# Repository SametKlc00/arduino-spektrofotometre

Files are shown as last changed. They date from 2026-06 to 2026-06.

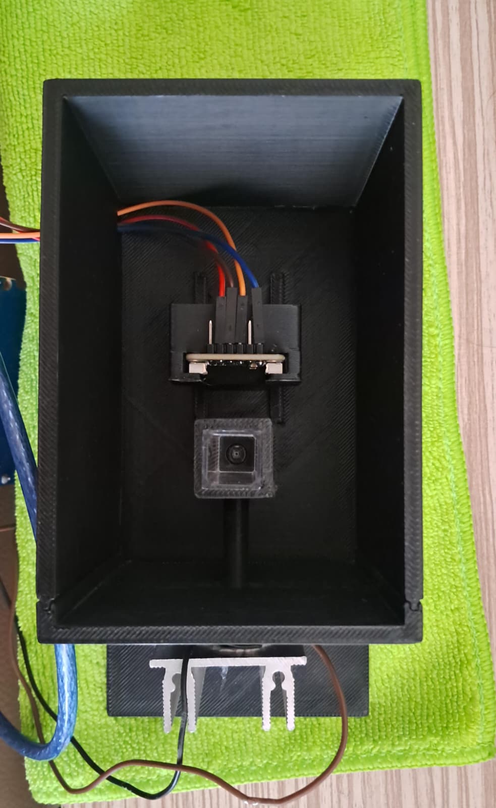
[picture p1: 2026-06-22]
spektrofotometre_devir_paketi_tsl2591/04_Gorseller/WhatsApp Image 2026-06-11 at 16.28.41.jpeg

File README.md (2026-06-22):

# Arduino Tabanlı Düşük Maliyetli Spektrofotometre

Bu proje, düşük maliyetli bir spektrofotometre prototipi geliştirmek amacıyla hazırlanmıştır. Sistem; LED ışık kaynağı, küvet yuvası, ışık sızdırmayan 3D baskı kutu, TSL2591 dijital ışık sensörü ve Arduino tabanlı ölçüm yazılımından oluşur.

## Projenin Amacı

Projenin amacı, belirli dalga boyundaki LED ışığının numuneden geçtikten sonra sensör tarafından ölçülmesi ve bu ölçümden geçirgenlik ile absorbans değerlerinin hesaplanmasıdır.

Bu sayede su, vişne suyu ve seyreltilmiş numuneler gibi örneklerde ışık geçirgenliği karşılaştırılabilir.

## Çalışma Prensibi

Optik yol:

```text
LED ışık kaynağı -> siyah optik tüp -> küvet -> TSL2591 ışık sensörü
```

Ölçüm sırasında üç temel değer alınır:

- **Dark:** LED kapalıyken alınan karanlık ölçüm
- **Blank:** LED açıkken saf su veya çözücü ile alınan referans ölçüm
- **Sample:** LED açıkken numune ile alınan ölçüm

Absorbans hesabı:

```text
I_blank = Blank - Dark
I_sample = Sample - Dark
T = I_sample / I_blank
A = -log10(T)
```

## Kullanılan Donanımlar

- Arduino Uno veya uyumlu geliştirme kartı
- TSL2591 dijital ışık sensörü
- 5 mm LED ışık kaynakları
- 520-525 nm yeşil LED
- 550 nm veya 565-570 nm yellow-green LED
- 590-600 nm amber/turuncu LED
- 650-660 nm kırmızı LED
- Küvet
- Siyah optik tüp
- Işık sızdırmayan 3D baskı kutu
- Jumper kablo, pin header ve dirençler

## TSL2591 Bağlantısı

| TSL2591 | Arduino Uno |
|---|---|
| SDA | A4 |
| SCL | A5 |
| VCC | 5V veya modüle göre 3.3V |
| GND | GND |

## Klasör Yapısı

| Klasör | Açıklama |
|---|---|
| `01_Kodlar` | Arduino ve Python ölçüm kodları |
| `02_Raporlar` | Proje raporları için ayrılan klasör |
| `03_PDF_Ciktilar` | PDF çıktıları |
| `04_Gorseller` | Devre, kutu ve ölçüm görselleri |
| `05_3D_Model_ve_Kutu` | 3D baskı kutu dosyaları |
| `06_Donanim_Notlari` | Parça listesi ve donanım notları |
| `07_Kullanim_El_Kitapcigi` | Kullanım kılavuzu |

## Kodlar

| Dosya | Açıklama |
|---|---|
| `01_Kodlar/tsl2591_olcum/tsl2591_olcum.ino` | TSL2591 sensöründen lux değeri okur |
| `01_Kodlar/tsl2591_absorbans_komutlu/tsl2591_absorbans_komutlu.ino` | Dark, blank ve sample ölçümleriyle absorbans hesabı yapar |
| `01_Kodlar/python_serial_csv_logger/tsl2591_csv_logger.py` | Seri porttan gelen verileri CSV dosyasına kaydeder |
| `01_Kodlar/arsiv_lm393/lm393_analog_absorbans.ino` | İlk LM393/LDR prototipinin arşiv kodudur |

## Ölçüm Sırası

1. Sensör ve LED bağlantıları kontrol edilir.
2. Kutu kapağı kapatılır.
3. LED kapalıyken dark ölçümü alınır.
4. Saf su veya çözücü ile blank ölçümü alınır.
5. Numune yerleştirilir ve sample ölçümü alınır.
6. Transmittance ve absorbans değeri hesaplanır.
7. Her numune için ölçüm birkaç kez tekrarlanır.

## Proje Gelişim Süreci

Proje ilk olarak LM393 LDR modülüyle başlatılmıştır. Daha sonra daha hassas ve kararlı ölçüm almak için TSL2591 dijital ışık sensörüne geçilmiştir.

Işık sızıntısını azaltmak ve ölçüm tekrarlanabilirliğini artırmak için 3D baskı kapalı kutu kullanılmıştır. Ölçümler dark, blank ve sample kalibrasyon adımlarıyla yapılmıştır.

## Not

Bu depo, projenin mezuniyet sonrası devredilebilmesi için düzenlenmiştir. Kodlar, parça listesi, kullanım kılavuzu ve rapor klasörleri birlikte sunulmuştur.

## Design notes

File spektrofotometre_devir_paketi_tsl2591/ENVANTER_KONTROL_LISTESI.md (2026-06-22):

# Teslim Envanteri Kontrol Listesi

| Durum | Dosya / Parça | Koyulacağı Klasör | Not |
| --- | --- | --- | --- |
| [ ] | LM393 Arduino kodları | 01_Kodlar/arsiv_lm393 | İlk analog prototip kodları. |
| [ ] | TSL2591 Arduino kodları | 01_Kodlar/tsl2591_olcum | Ana dijital sensör kodları. |
| [ ] | Python CSV kayıt arayüzü | 01_Kodlar/python_serial_csv_logger | Serial Monitor kapalıyken veri kaydı için. |
| [ ] | Haftalık, vize ve final raporları | 02_Raporlar | Word/PDF sürümleri bu klasöre eklenmeli. |
| [ ] | Kutu farkı raporu | 02_Raporlar | Açık ortam ve kapalı kutu karşılaştırması. |
| [ ] | Vişne suyu test raporu | 02_Raporlar | Seyreltme ölçümleri ve doğruluk yorumu. |
| [ ] | Ekran görüntüleri ve devre fotoğrafları | 04_Gorseller | Arduino, Python, sensör ve kutu fotoğrafları. |
| [ ] | 3D kutu STL/3MF/CAD dosyaları | 05_3D_Model_ve_Kutu | Kutu yeniden basılacaksa gerekli. |
| [ ] | Satın alma linkleri ve faturalar | 06_Donanim_Notlari | Hocanın parçaları tekrar alabilmesi için. |
| [ ] | Kullanım el kitapçığı PDF/DOCX | 07_Kullanim_El_Kitapcigi | Bu paket içinde hazır verildi. |

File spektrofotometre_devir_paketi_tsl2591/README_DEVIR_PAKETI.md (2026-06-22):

# Arduino Tabanlı Düşük Maliyetli Spektrofotometre - Devir Paketi

Hazırlanma tarihi: 2026-06-22

Bu paket, spektrofotometre projesinin mezuniyet sonrası hocaya düzenli şekilde devredilmesi için hazırlanmıştır. Ana sürüm TSL2591 dijital ışık sensörü, Arduino, LED ışık kaynakları, küvet ve ışık sızdırmayan 3D kutu üzerine kuruludur.

## Klasör Yapısı

| Klasör | İçerik |
| --- | --- |
| 01_Kodlar | Arduino ve Python veri kayıt kodları |
| 02_Raporlar | Haftalık, vize, final, kutu farkı ve vişne suyu raporları için alan |
| 03_PDF_Ciktilar | Nihai PDF çıktıları için alan |
| 04_Gorseller | Devre, kutu, sensör, ölçüm ve ekran görüntüleri |
| 05_3D_Model_ve_Kutu | STL/3MF/CAD dosyaları ve baskı notları |
| 06_Donanim_Notlari | Parça listesi, satın alma ve bağlantı notları |
| 07_Kullanim_El_Kitapcigi | PDF, DOCX ve Markdown kullanım kılavuzu |

## Teslimden Önce

Eski raporlar, fotoğraflar, Arduino ekran görüntüleri, Python arayüz çıktıları ve 3D kutu dosyaları ilgili klasörlere eklenmelidir. Bu paket ana iskeleti ve güncel kullanım dokümanını hazır verir.

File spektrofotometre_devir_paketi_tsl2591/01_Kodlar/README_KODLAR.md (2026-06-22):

# Kodlar

## tsl2591_olcum
TSL2591 sensörünün çalışıp çalışmadığını lux değeriyle test eder.

## tsl2591_absorbans_komutlu
Serial Monitor üzerinden `d`, `b`, `s` komutlarıyla dark, blank ve sample ölçümü alır. Absorbans hesabı örneğini içerir.

## python_serial_csv_logger
Arduino Serial Monitor kapalıyken ölçüm çıktısını CSV dosyasına kaydeder. `PORT` değeri bilgisayardaki COM portuna göre güncellenmelidir.

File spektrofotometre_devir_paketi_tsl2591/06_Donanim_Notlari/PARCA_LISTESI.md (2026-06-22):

# Son Donanım Parça Listesi

| No | Parça | Durum | Not |
| --- | --- | --- | --- |
| 1 | TSL2591 dijital ışık sensörü | Ana sensör / var | I2C haberleşme, yüksek hassasiyetli ışık ölçümü. Arduino Uno bağlantısı: SDA A4, SCL A5, VCC 5V veya modüle göre 3.3V/5V, GND. |
| 2 | Arduino Uno veya uyumlu kart | Ana kontrol kartı / var | Serial Monitor ve Python arayüzü için 9600 baud kullanılabilir. ESP8266/AS7262 geçişi yapılırsa ayrı klasörde opsiyonel not olarak tutulmalıdır. |
| 3 | 5 mm yeşil LED 520-525 nm | Alınacak / önerilen | Vişne suyu gibi kırmızı renkli numunelerde fark oluşturmak için uygundur. Ürün açıklamasında nm değeri yazmalıdır. |
| 4 | 5 mm yellow-green LED 550 veya 565-570 nm | Alınacak / 550 nm'e yakın | 550 nm doğrudan bulunamazsa 565-570 nm seçilebilir. Raporda kullanılan gerçek dalga boyu yazılmalıdır. |
| 5 | 5 mm amber/turuncu LED 590-600 veya 600-610 nm | Alınacak / ikinci kanal | Farklı dalga boyunda karşılaştırmalı ölçüm için kullanılabilir. |
| 6 | 5 mm kırmızı LED 650-660 nm | Alınacak / üçüncü kanal | Kırmızı dalga boyunda kontrol ölçümü için uygundur. |
| 7 | 220 ohm ve 330 ohm direnç seti | Alınacak / yedek | LED testlerinde akımı sınırlamak için. Her LED ayrı blank kalibrasyonu ile kullanılmalıdır. |
| 8 | Sabit akım LED sürücü modülü | Önerilen geliştirme | LED parlaklığını daha kararlı tutar; ölçüm tekrarlanabilirliğini artırır. |
| 9 | Lehimli pin header, jumper kablo, makaron | Alınacak / yedek | Sensör pinlerinde temassızlığı azaltmak için pin header lehimlenmeli, kablo mekanik olarak sabitlenmelidir. |
| 10 | Küvet | Var / yedek alınabilir | Blank ve numune ölçümlerinde aynı yönle yerleştirilmelidir. |
| 11 | Siyah optik tüp ve 3D baskı kutu | Var / dosyası eklenmeli | LED - tüp - küvet - sensör hizasını sabitler, ortam ışığını azaltır. |
| 12 | USB kablo ve 5V adaptör | Alınacak / yedek | Zayıf USB kablo ölçümde gürültü ve bağlantı sorunlarına neden olabilir. |

## LED Kararı

Ana yeşil ölçüm için 520-525 nm 5 mm yeşil LED alınabilir. 550 nm özellikle isteniyorsa 550 nm veya 565-570 nm yellow-green LED seçilmeli ve raporda gerçek nm değeri yazılmalıdır. 590-600 nm amber ve 650-660 nm kırmızı LED karşılaştırmalı ölçümler için eklenebilir.

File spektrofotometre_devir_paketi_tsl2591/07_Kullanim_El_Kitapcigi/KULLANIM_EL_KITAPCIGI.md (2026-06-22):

# Kullanım El Kitapçığı

## Amaç

Bu el kitapçığı, Arduino tabanlı düşük maliyetli spektrofotometre projesinin mezuniyet sonrası hocaya devredilmesi için hazırlanmıştır. Ana sürümde TSL2591 dijital ışık sensörü, LED ışık kaynağı, küvet yuvası ve ışık sızdırmayan 3D baskı kutu kullanılmaktadır.

## Projenin Gelişim Özeti

Proje ilk olarak LM393 LDR modülüyle kaba ışık ölçümü yapacak şekilde başlatıldı. Daha sonra ölçüm hassasiyetini artırmak için TSL2591 dijital ışık sensörüne geçildi. Kutu, LED hizası ve dark/blank/sample kalibrasyon adımları geliştirilerek tekrarlanabilir absorbans hesabı hedeflendi.

## Çalışma Prensibi

LED ışık kaynağından çıkan ışık siyah optik tüpten geçer, küvetteki blank veya numuneden geçtikten sonra TSL2591 sensöre ulaşır. Sensör ışık şiddetini dijital olarak okur. Dark ve blank değerleri kullanılarak numune için transmittance ve absorbans hesaplanır.

## Optik Yol

Son kutu mantığında optik yol şu şekildedir: LED solda, siyah tüp ortada, küvet yuvası tüpten sonra, TSL2591 sensör ise karşı tarafta konumlanır. LED, küvet ve sensör aynı eksende tutulmalıdır. Kutu kapalıyken dış ortam ışığı minimum olmalıdır.

## Sensör Bağlantısı

TSL2591, Arduino Uno üzerinde I2C ile bağlanır. SDA pini A4'e, SCL pini A5'e, VCC pini modülün desteklediği beslemeye, GND pini GND'ye bağlanır. Modül 5V uyumlu değilse 3.3V kullanılmalıdır. Pin yuvalarında temassızlık olmaması için header lehimlenmeli ve kablolar sabitlenmelidir.

## LED Seçimi

Dalga boyunu kontrol etmek için rastgele renk LED paketleri yerine açıklamasında nm değeri yazan 5 mm LED seçilmelidir. Vişne suyu ölçümleri için 520-525 nm yeşil LED uygundur. 550 nm hedefleniyorsa 550 nm veya bulunamazsa 565-570 nm yellow-green LED alınabilir. Karşılaştırma için 590-600 nm amber ve 650-660 nm kırmızı LED eklenebilir.

## Kalibrasyon Mantığı

Her ölçüm serisinde önce dark, sonra blank, sonra sample alınır. Dark ölçümde LED kapalı ve kutu kapalıdır. Blank ölçümde LED açık, küvette saf su veya çözücü vardır. Sample ölçümde aynı LED açıkken numune küveti yerleştirilir.

## Absorbans Hesabı

Karanlık düzeltmesi yapıldıktan sonra I_blank = Blank - Dark ve I_sample = Sample - Dark hesaplanır. Transmittance T = I_sample / I_blank olarak bulunur. Absorbans A = -log10(T) formülüyle hesaplanır. T değeri 0 ile 1 arasında olmalıdır.

## Vişne Suyu Ölçüm Akışı

Vişne suyu testlerinde önce saf su blank olarak alınır. Ardından vişne suyu ve suyla seyreltilmiş numuneler sırayla ölçülür. Önerilen sıra: doğrudan vişne suyu, 5 pipet su eklenmiş az seyreltilmiş numune, 10 pipet su eklenmiş orta numune, 15 pipet su eklenmiş çok seyreltilmiş numune ve 20 pipet su eklenmiş aşırı seyreltilmiş numune.

## Veri Kaydı

Önerilen CSV kolonları: tarih_saat, sample_id, led_nm, dark_lux, blank_lux, sample_lux, transmittance, absorbance, tekrar_no, not. Her numune için en az 3 tekrar alınması, sonucun ortalama ve sapma ile raporlanması önerilir.

## Sorun Giderme

Sensör değeri zıplıyorsa önce kablo teması, lehim, USB güç kaynağı, LED kararlılığı ve kutu kapağı kontrol edilir. Absorbans negatif çıkarsa sample blanktan daha fazla ışık geçiriyor olabilir; blank/sample sırası, küvet yönü ve ışık sızıntısı tekrar kontrol edilmelidir.

## Hocaya Devir Notu

Paket içinde kodlar, rapor yer tutucuları, parça listesi, envanter kontrol listesi, kullanım el kitapçığı ve hocaya gönderilebilecek kısa açıklama metni vardır. Eski raporlar, fotoğraflar ve STL dosyaları ilgili klasörlere eklenerek teslim klasörü tamamlanmalıdır.

## Opsiyonel İleri Sürüm Notu

Proje ileride AS7262/AS726x gibi çok kanallı spektral sensöre taşınırsa bu paket içindeki TSL2591 ana sürümü arşiv olarak korunmalı, yeni ESP8266/AS7262 kodları ayrı alt klasörde tutulmalıdır. Böylece proje geçmişi karışmadan izlenebilir.

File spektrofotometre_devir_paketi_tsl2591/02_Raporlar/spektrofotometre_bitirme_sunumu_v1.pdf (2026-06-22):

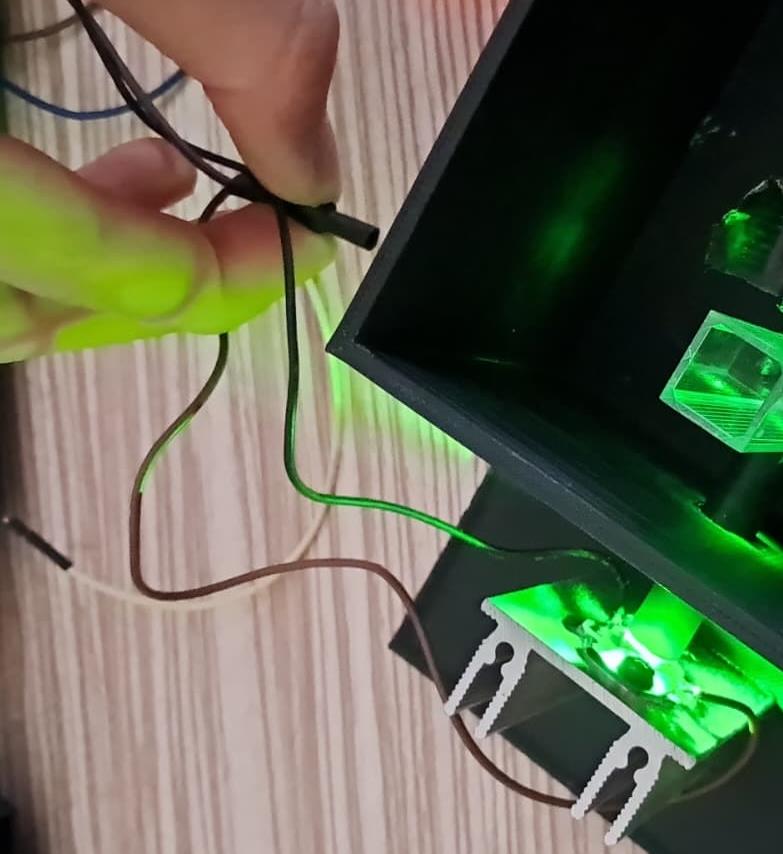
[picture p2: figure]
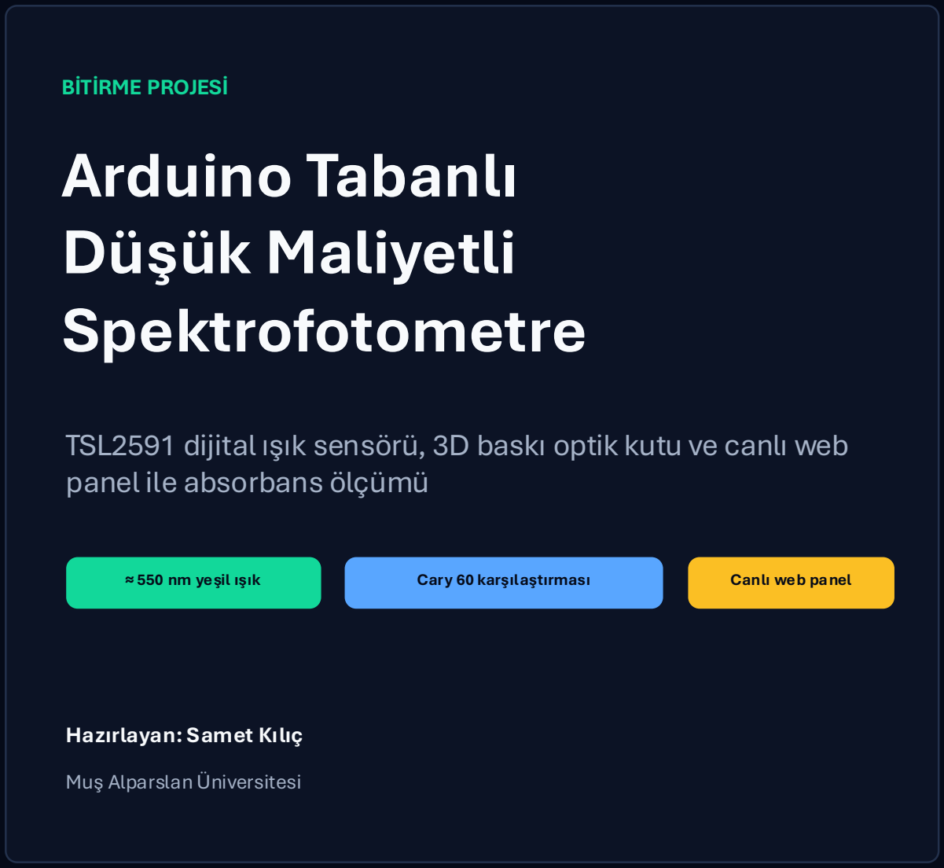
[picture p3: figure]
BİTİRME PROJESİ Arduino Tabanlı Düşük Maliyetli Spektrofotometre; panel ile absorbans ölçümü; ≈ 550 nm yeşil ışık; Cary 60 karşılaştırması; Canlı web panel; Hazırlayan: Samet Kılıç; Muş Alparslan Üniversitesi

## TSL2591 dijital ışık sensörü, 3D baskı optik kutu ve canlı web

Arduino Tabanlı Düşük Maliyetli Spektrofotometre | 01

Prensip

# Spektrofotometre mantığı

Spektrofotometre, bir maddenin belirli dalga boyundaki ışığı ne kadar geçirdiğini veya ne kadar soğurduğunu ölçen cihazdır. Numune ışığın bir kısmını soğurur. Sensöre ulaşan ışık azaldıkça transmittance düşer, absorbans artar.

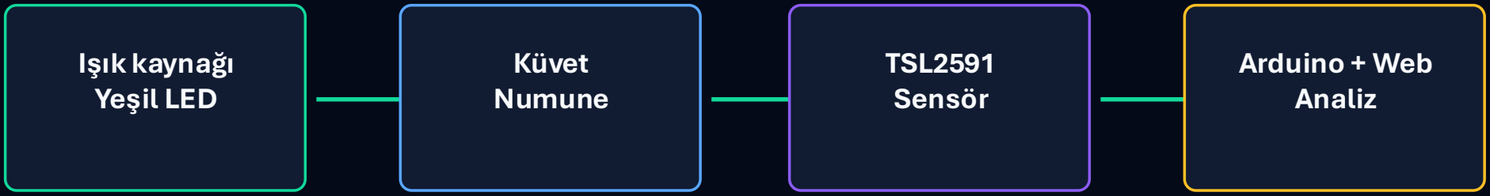
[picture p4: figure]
Işık kaynağı Yeşil LED; Küvet Numune; TSL2591 Sensör; Arduino + Web Analiz

## Daha koyu numune → daha düşük Raw → daha yüksek Absorbance

Spektrofotometre;
- kimya laboratuvarlarında,
- biyoloji ve biyokimya analizlerinde,
- gıda analizlerinde,
- ilaç sektöründe,
- su ve çevre analizlerinde,
- kan/idrar gibi klinik örnek analizlerinde,
- bitki, tanen, protein, şeker, pigment gibi madde tayinlerinde
çok sık kullanılır.

Gelişim

# Nereden nereye geldik?

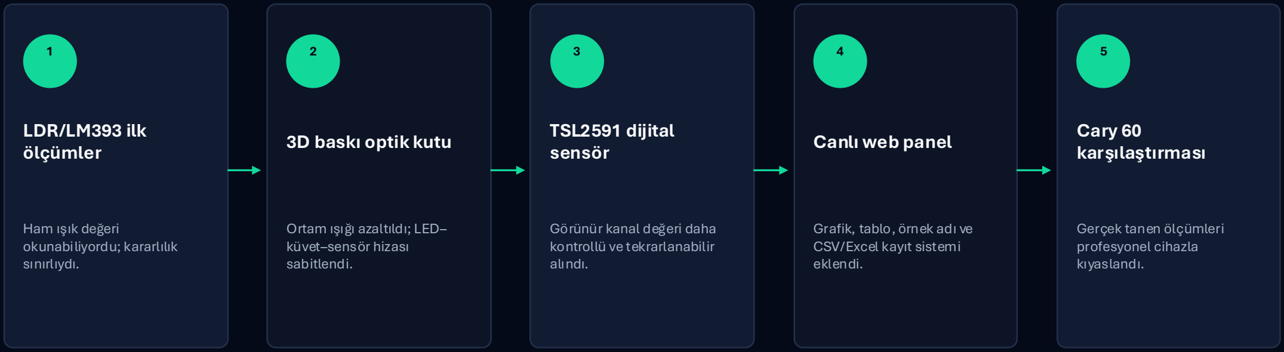
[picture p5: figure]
LDR/LM393 ilk ölçümler; Ham ışık değeri okunabiliyordu; kararlılık sınırlıydı.; 3D baskı optik kutu; Ortam ışığı azaltıldı; LED– küvet–sensör hizası sabitlendi.; TSL2591 dijital sensör; Görünür kanal değeri daha kontrollü ve tekrarlanabilir alındı.; Canlı web panel; Grafik, tablo, örnek adı ve CSV/Excel kayıt sistemi eklendi.; Cary 60 karşılaştırması; Gerçek tanen ölçümleri profesyonel cihazla kıyaslandı.

Sistem

# Donanım mimarisi

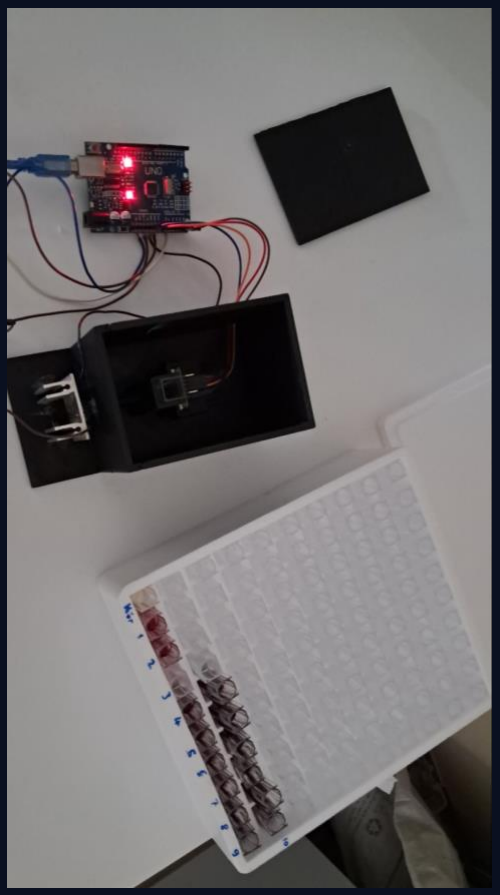
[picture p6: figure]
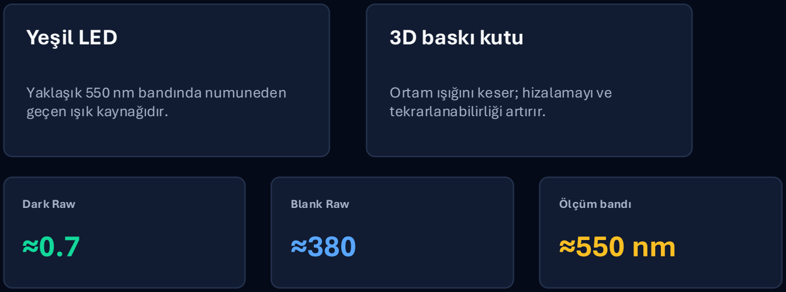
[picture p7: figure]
Yeşil LED; Yaklaşık 550 nm bandında numuneden geçen ışık kaynağıdır.; 3D baskı kutu; Ortam ışığını keser; hizalamayı ve tekrarlanabilirliği artırır.; Dark Raw ≈0.7; Blank Raw ≈380; Ölçüm bandı ≈550 nm

Arduino U no + TSL2591 + 3D baskı optik kutu

## Arduino Uno

Sensör verisini okur ve seri porttan DATA satırı gönderir.

## TSL2591

Full ve IR kanallarından görünür ışık değeri hesaplanır.

Yazılım

# Yazılım mimarisi: ölçümden grafiğe

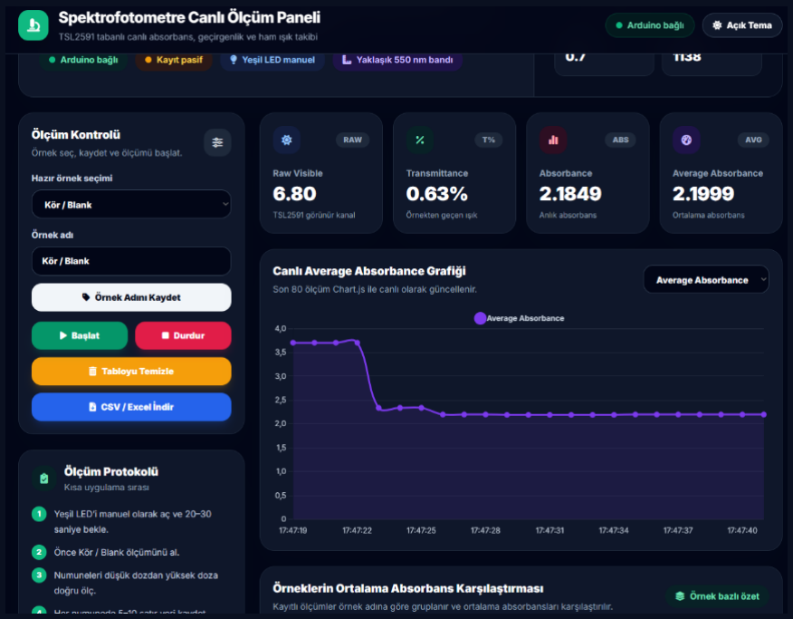
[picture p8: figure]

Canlı ölçüm paneli: grafik, tablo ve CSV

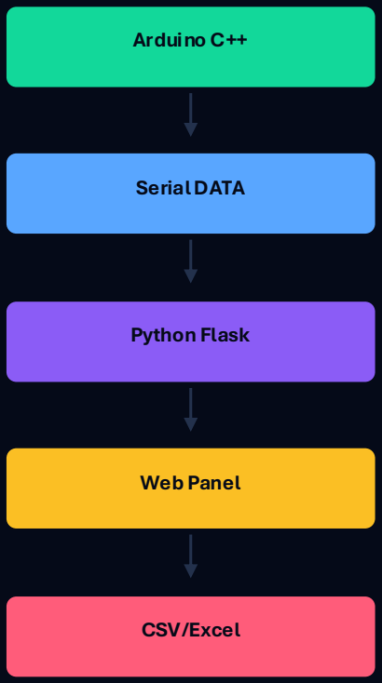
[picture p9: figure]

Arduino C++ | TSL2591 verisi okunur
Serial DATA | DATA,Raw,T%,Abs,AvgAbs
Python Flask | Veri parse edilir ve API güncellenir
Web Panel | Chart.js grafik + canlı tablo
CSV/Excel | Ölçüm çıktısı dışa aktarılır

Deney

# Ölçüm protokolü

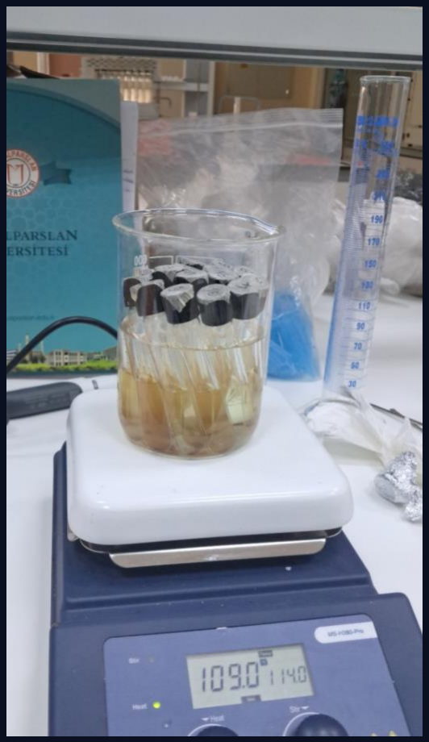
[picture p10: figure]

Isıtma/renk oluşumu sonrası tüpler

## 1 Dark kontrol

Işık kapalı + kutu kapalı → Raw ≈ 0.7

## 2 Kör / Blank

Kör çözelti referans alınır; analizde kör çıkarma uygulanır.

## 3 Numuneler

Düşük tanen miktarından yüksek miktara doğru ölçülür.

## 4 Karşılaştırma

Prototip sonuçları Cary 60 verileriyle birlikte yorumlanır.

# Dark Raw: Işık kapalıyken sensörün okuduğu taban

değer.

# Blank Raw: Işık açıkken kör çözeltiden geçen

referans ışık değeri.

# Kör: Analiz maddesi içermeyen, sadece çözücü/reaktif içeren

referans çözelti.

Sonuç

# Prototip ölçüm sonuçları

# Ana gözlem

### Tanen miktarı arttıkça ortalama absorbans

genel olarak yükseldi.

### İlk artış keskin; yüksek konsantrasyonda

sensör düşük ışık sınırına yaklaştı.

### 3. tüp kırıldığı için 0.002 g grubunda 2 tekrar

kaldı.

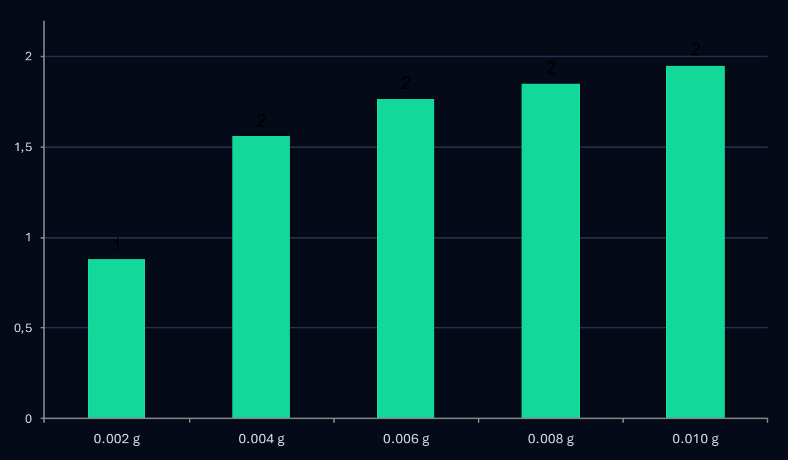
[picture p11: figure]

Kör düzeltmesi: Numune Avg Abs − Kör Avg Abs (≈0,4056)

Doğrulama

# Prototip ve Cary 60 karşılaştırması

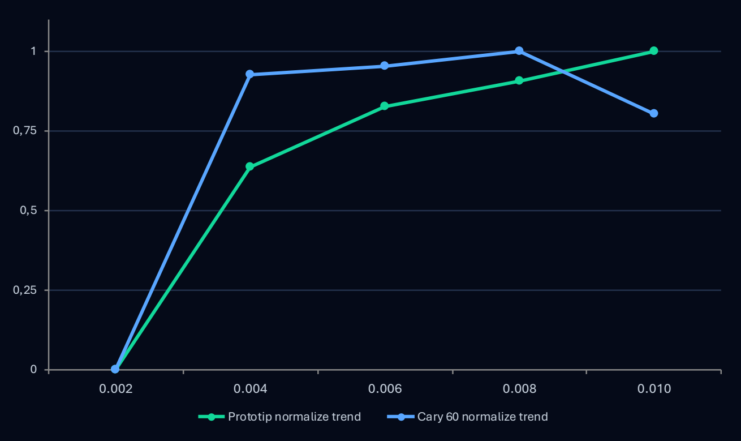
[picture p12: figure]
Prototip normalize trend; Cary 60 normalize trend
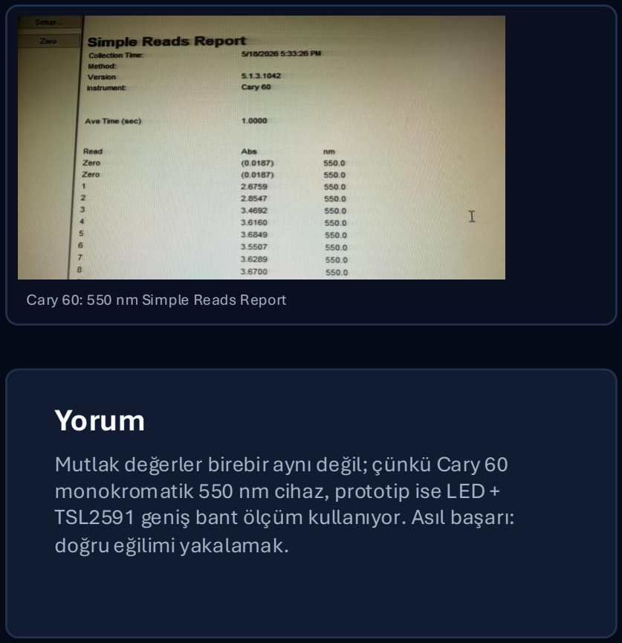
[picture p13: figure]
Cary 60: 550 nm Simple Reads Report; Yorum; doğru eğilimi yakalamak.

Mutlak değerler birebir aynı değil; çünkü Cary 60 monokromatik 550 nm cihaz, prototip ise LED + TSL2591 geniş bant ölçüm kullanıyor. Asıl başarı:

Kod

# Kodun kritik hesaplama kısmı

## Arduino C++

float visible = full - ir;
float I_blank = blankRaw - darkRaw; float I_sample = rawValue - darkRaw;

float T = I_sample / I_blank;
float A = -log10(T);

Serial.print("DATA,");
Serial.print(avgRaw);

## Python Flask

line = ser.readline().decode().strip() if line.startswith("DATA,"):
raw, t, abs, avg = parse(line) latest_data = {...}
if measurement_enabled:
save_to_csv(row)

sensör → görünür ışık → transmittance → absorbance → web panel.

Bu kodda TSL2591’den görünür ışık değeri okunur, karanlık ve blank referansları çıkarılır, transmittance ve absorbans hesaplanır, ardından sonuçlar web paneline gönderilir.

Python / Flask Veri Akışı
Arduino’dan gelen seri port satırı okunur.
Satır DATA, ile başlıyorsa ölçüm verisi olarak kabul edilir.
Raw, Transmittance, Absorbance ve Average Absorbance değerleri ayrıştırılır. Son değerler web panelinde gösterilmek üzere güncellenir.
Kayıt aktifse ölçüm satırı CSV/Excel dosyasına kaydedilir.

Değerlendirme

# Doğru çalışanlar, sınırlılıklar ve gelecek adımlar

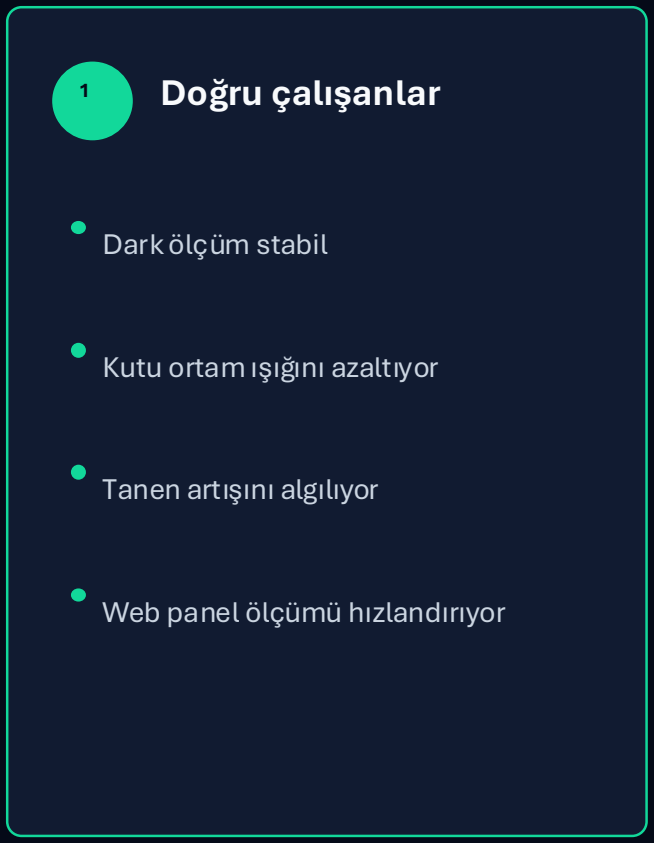
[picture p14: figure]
1 Doğru çalışanlar; Dark ölçüm stabil; Kutu ortam ışığını azaltıyor; Tanen artışını algılıyor; Web panel ölçümü hızlandırıyor
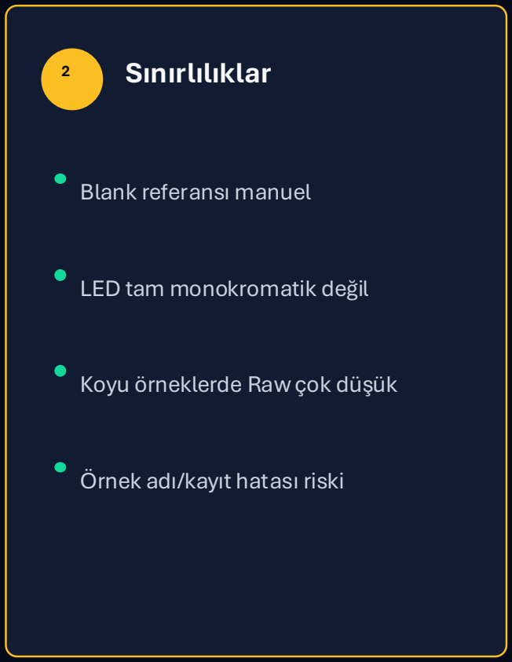
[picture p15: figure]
2 Sınırlılıklar; Blank referansı manuel; LED tam monokromatik değil; Koyu örneklerde Raw çok düşük; Örnek adı/kayıt hatası riski

## 3 Geliştirme planı

550 nm’ye daha yakın LED kullanılacak.

R², standart sapma ve hata analizi panelde otomatik gösterilecek.

Farklı numunelerle tekrar test yapılacak

Farklı dalga boyları

Sunum Planı

# Akış

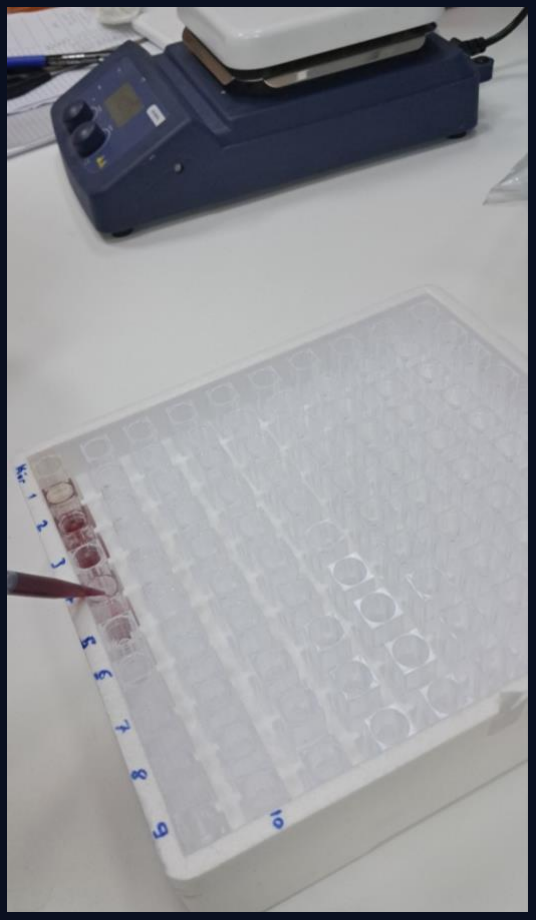
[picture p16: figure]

Numune hazırlığı ve ölçüm sırası

1

## Kısa tanıtım

Cihazın ışık–küvet–sensör mantığını gösterdik.

2

## Dark kontrol

Işık kapalıyken Raw ≈ 0.7 olduğunu anlattık

3

## Blank / kör

Profesyonel cihazdaki Zero işlemini prototipte kör düzeltmesiyle yaptığını açıkladık.

4

## Numune ölçümü

Koyu örnekte Raw düşer, Absorbance yükselir.

5

## Sonuç ve gelecek

Uygun trend + geliştirme planı ile bitirdik.

Bu proje, pahalı cihazınyerine geçmek içindeğil, temel spektrofotometrik ölçümü düşük maliyetli ve geliştirilebilir bir prototiple göstermek için tasarlandı.

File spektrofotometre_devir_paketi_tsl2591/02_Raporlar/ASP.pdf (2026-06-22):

# ARDUINO TABANLI DÜŞÜK MALİYETLİ SPEKTROFOTOMETRE PROTOTİPİ

## Gelişim Süreci, Doğrulama Testleri, Mevcut Durum ve Tez / TÜBİTAK / Teknofest Potansiyel Değerlendirmesi

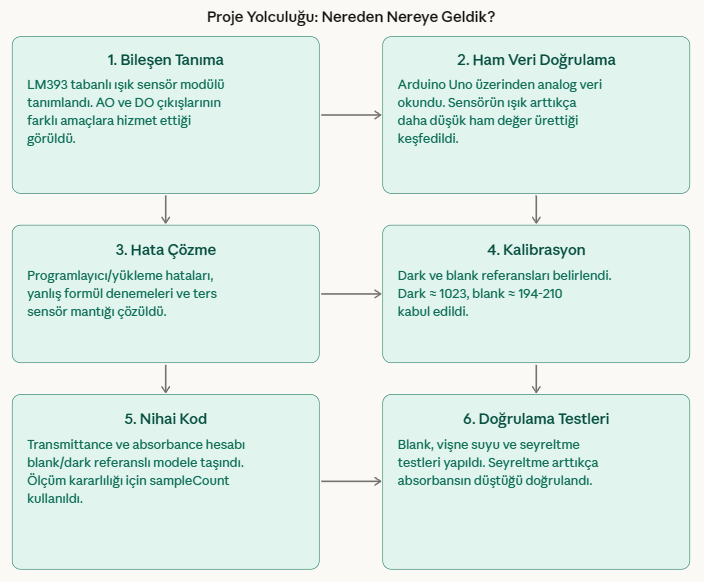
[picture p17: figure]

Hazırlayan: Samet Kılıç
Tarih: Nisan 2026

Projenin amacı

Düşük maliyetli bileşenlerle temel spektrofotometre mantığını çalışan bir prototip olarak göstermek ve gerçek örneklerde göreli absorbans değişimini ölçmek.

Şu anki durum | Dark, blank ve vişne suyu seyreltme testleri tamamlandı. Sistem, derişim azaldıkça absorbansın düştüğünü düzenli biçimde gösterebiliyor.
En güçlü çıktı | Seyreltilmemiş vişne suyu → en yüksek absorbans; seyrelme arttıkça absorbansın kademeli düşmesi.
Mevcut seviye | Prototip / doğrulama seviyesi. Çalışma prensibi doğru, mutlak laboratuvar hassasiyeti için ise daha iyi dedektör ve optik kararlılık gerekiyor.

## 1. Yönetici Özeti

Bu belge, geliştirilen düşük maliyetli spektrofotometre prototipinin yalnızca son hâlini değil; hangi ihtiyaçtan doğduğunu, hangi teknik sorunların aşıldığını, hangi doğrulama testlerinin yapıldığını ve şu anda ne seviyeye ulaştığını bütünlüklü biçimde göstermeyi amaçlar.

Çalışmanın çıkış noktası, ticari spektrofotometrelerin yüksek maliyetine karşı daha erişilebilir bir alternatif oluşturma düşüncesidir. Bu doğrultuda Arduino Uno, LM393 tabanlı fotodiyot ışık sensör modülü, yeşil ışık kaynağı, küvet ve kapalı ölçüm kutusu kullanılarak işlevsel bir optik ölçüm düzeneği kurulmuştur.

Prototip; ışık kaynağı, örnek, optik yol ve dedektör zinciri üzerinden spektrofotometrik mantıkla çalışmaktadır. Dark ve blank referansları alınmakta, örnekten geçen ışık miktarına göre geçirgenlik ve absorbans hesaplanmaktadır.

Yapılan testlerde dark ölçümünde ham değerin yaklaşık 1023, blank ölçümünde ise yaklaşık 194–210 aralığında olduğu görülmüştür. Daha sonra vişne suyu üzerinde yapılan yoğunluk ve seyreltme deneylerinde seyreltilmemiş örneğin en yüksek absorbansı verdiği, su miktarı arttıkça absorbansın düzenli biçimde azaldığı doğrulanmıştır.

Bu sonuçlar, prototipin yalnızca çalıştığını değil; fiziksel olarak beklenen yönde davrandığını göstermektedir. Bu nedenle sistem; bitirme projesi açısından başarılı, tez genişletmesi açısından geliştirilebilir ve doğru konumlandırıldığında TÜBİTAK / Teknofest başvurusu için potansiyel taşıyan bir çekirdek platform olarak değerlendirilebilir.

Kısa değerlendirme: Bu çalışma bir ürün değil, çalışan ve doğrulanmış bir prototiptir. En büyük değeri, düşük maliyetli bir optik ölçüm fikrini çalışır hâle getirmiş ve ölçüm eğilimini deneysel olarak doğrulamış olmasıdır.

## 2. Problem, İhtiyaç ve Hedeflenen Çözüm

Bu proje ile çözülmek istenen temel problem, spektrofotometrik ölçüm mantığını erişilebilir maliyetle gösterebilen, eğitim ve araştırma amaçlı geliştirilebilir bir prototip oluşturmaktır.

Başlangıçtaki ihtiyaç | Hedeflenen teknik cevap | Bugün ulaşılan durum
Yüksek maliyetli cihazlara alternatif arayışı | Düşük maliyetli bir optik ölçüm prototipi kurmak | İşlevsel prototip kuruldu ve temel deneyler tamamlandı.
Ölçüm mantığının görünür olması | Işık–örnek–dedektör zincirini açıkça kurmak | Kapalı kutu, küvet, yeşil ışık ve sensör ile optik yol oluşturuldu.
Nicel yorum ihtiyacı | Transmittance ve absorbance hesabı üretmek | Dark/blank referanslı nihai kod ile sayısal sonuç alındı.
Gerçek örneklerle doğrulama | Seyreltme etkisinin ölçülebilmesi | Vişne suyu üzerinde derişim değişimi başarıyla gözlendi.

## 3. Kurulan Prototip Düzenek

Aşağıdaki görseller prototipin genel yerleşimini, aktif ışık yolunu ve kullanılan sensör modülünün fiziksel yapısını göstermektedir.

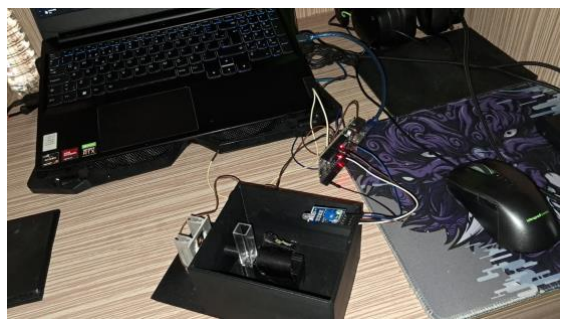
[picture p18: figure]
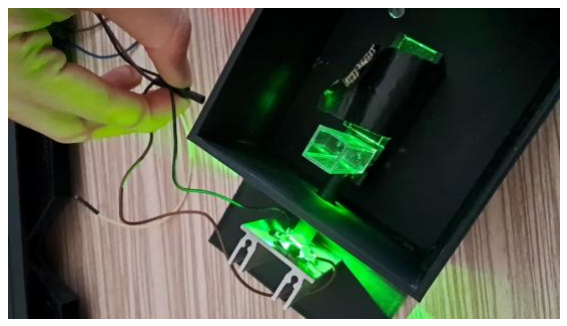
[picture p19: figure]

Genel prototip görünümü | Işık kaynağı aktifken optik yol

## 4. Çalışma Prensibi ve Ölçüm Mantığı

Sistem, temel spektrofotometre mantığıyla; yani ışık kaynağı → örnek (küvet) → dedektör zinciri üzerinden çalışmaktadır. Işık, küvet içerisindeki örnekten geçtikten sonra sensöre ulaşmakta; sensörün AO çıkışı üzerinden analog veri okunmaktadır.

Kullanılan sensör modülü klasik laboratuvar tipi fotometre dedektörü olmasa da, üzerine düşen ışık miktarına göre değişen analog bir sinyal üretebildiği için prototip düzeyinde optik ölçüm yapmak mümkün olmuştur.

Ölçüm yorumunda iki referans kritik rol oynamıştır: dark ve blank. Dark, ışık kapalıyken alınan karanlık referansıdır. Blank ise ışık açık ve boş küvet varken alınan referans ölçümdür. Nihai kod, ham veriyi doğrudan kullanmak yerine bu iki referans üzerinden göreli ışık büyüklüğü kurmaktadır.

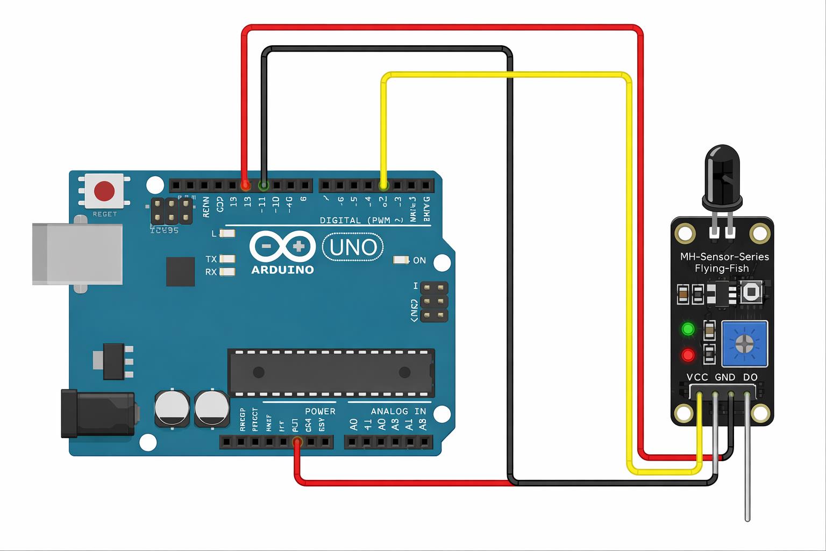
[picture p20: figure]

Şekil 1. Arduino Uno ile sensör modülü arasındaki bağlantı şeması.

Hat | Bağlantı | Projede görevi | Not
AO | Arduino A0 | Ham analog ışık verisini okumak | Aktif kullanılan ana ölçüm hattı
VCC | Arduino 5V | Sensör beslemesi | Modül 5 V ile çalıştırıldı
GND | Arduino GND | Ortak toprak | Ölçüm kararlılığı için zorunlu
DO | Dijital pin (isteğe bağlı) | Eşik tabanlı dijital çıkış | Nicel ölçüm için kullanılmadı

## 5. Nereden Nereye Geldik?

Aşağıdaki şema, proje sürecinde izlenen gelişim basamaklarını ve her adımda hangi teknik kararın alındığını özetlemektedir.

Şekil 2. Bileşen tanımadan seyreltme testlerine kadar proje yolculuğu.

Aşama | Başlangıçtaki sorun | Yapılan işlem | Çıkan sonuç
Sensör tanıma | Modülün tam olarak nasıl davranacağı bilinmiyordu | AO hattından doğrudan analog veri okundu | Sensörün veri ürettiği doğrulandı
Işık tepkisi | Ham veri nasıl yorumlanmalı bilinmiyordu | Telefon flaşı ile ışık artırma deneyi yapıldı | Sensörün ters mantıklı olduğu keşfedildi
Formülleme | Doğrudan yüzdeleme fiziksel olarak yanlış sonuç verdi | Dark ve blank referanslı modele geçildi | Blank ölçümünde absorbans sıfıra yaklaştı
Kararlılık | Tek ölçümde dalgalanma vardı | sampleCount ile ortalama alma eklendi | Average absorbance kararlı hale geldi
Doğrulama | Sistem gerçekten derişim ayırt ediyor mu? | Vişne suyu seyreltme serisi denendi | Absorbansın seyreltmeyle düştüğü doğrulandı

## 6. Karşılaşılan Temel Teknik Sorunlar ve Çözümler

Sorun | Neden kritik | Çözüm
Arduino yükleme / programlayıcı hatası | Kod yüklenmeden deneylerin ilerlemesi mümkün değildi | Kart-port ayarları ve bağlantılar sadeleştirilerek iletişim doğrulandı.
AO–DO karışıklığı | DO hattı nicel ölçüm için yetersizdi | AO hattı ana ölçüm kanalı olarak seçildi.
Sensörün ters davranışı | Ham değeri doğrudan ışık şiddeti sanmak yanlış sonuç veriyordu | darkRaw - rawValue yaklaşımı ile fiziksel yorum düzeltildi.
Blank absorbansının sıfıra yaklaşmaması | Formül ve referans seçimi yeterince iyi değildi | blankRaw deneysel olarak belirlendi ve nihai kod güncellendi.
Fiziksel hizalama / ortam ışığı | Ölçümler dalgalanabiliyordu | Kapalı kutu, sabit geometri ve çoklu örnekleme ile kararlılık artırıldı.

## 7. Doğrulama Testleri ve Referans Sonuçlar

Test | Koşul | Ham değer | Ana sonuç | Yorum
Dark testi | Işık kapalı, boş küvet, karanlık ortam | ≈ 1023 | T ≈ %0.01, A ≈ 4.0000 | Sistem karanlık referansını doğru okuyabiliyor.
Blank testi | Işık açık, boş küvet | ≈ 194–210 | T ≈ %98.78–100, A ≈ 0–0.0053 | Blank koşulunda absorbans sıfıra çok yakın.
Saf su kontrolü | Işık açık, küvette yalnız su | ≈ 36 | T ≈ %100, A ≈ 0.0000 | Sistem suyu blanke çok yakın görüyor.

Bu referans sonuçlar, prototipin önce sınır koşullarını (dark ve blank), ardından da optik olarak neredeyse blanke yakın davranan su örneğini doğru yönde yorumladığını göstermektedir.

## 8. Vişne Suyu Deneyi: Ölçülen Derişim Serisi

Bugün yapılan deneylerde vişne suyu, farklı miktarlarda su eklenerek seyreltilmiş ve her örnek için ortalama absorbans değeri değerlendirilmiştir. Bu deneyin amacı, derişim azaldıkça absorbansın kademeli olarak düşüp düşmediğini sınamaktır.

Örnek | Hazırlama yöntemi | Beklenen yön | Deney durumu
Seyreltilmemiş vişne suyu | Saf vişne suyu | En yüksek absorbans | Ölçüldü
Az seyreltilmiş | 5 pipet su eklendi | Absorbansın düşmesi | Ölçüldü
Orta seyreltilmiş | 10 pipet su eklendi | Absorbansın daha da düşmesi | Ölçüldü
Çok seyreltilmiş | 15 pipet su eklendi | Blanke yaklaşma eğilimi | Ölçüldü
Aşırı seyreltilmiş | 20 pipet su eklendi | Blanke daha fazla yaklaşma | Henüz raporlanmadı

Örnek | Raw aralığı | Transmittance (%) | Absorbance | Raporlanacak ortalama
Vişne suyu | 926–931 | 11–12 | 0.93–0.95 | ≈ 0.93
Az seyreltilmiş (5 pipet) | 867–871 | 18–19 | 0.72–0.73 | ≈ 0.72
Orta seyreltilmiş (10 pipet) | 837–840 | 22–23 | 0.65 civarı | ≈ 0.65
Çok seyreltilmiş (15 pipet) | 680–712 | 38–42 | 0.38–0.42 | ≈ 0.40
Saf su kontrolü | ≈ 36 | ≈ 100 | ≈ 0.00 | ≈ 0.00

Not: Çok seyreltilmiş örnek için birden fazla tekrar ölçümü yapılmış ve average absorbance değerleri yaklaşık 0.3829, 0.3904 ve 0.4214 olarak gözlenmiştir. Bu tekrarların ortalaması yaklaşık 0.3982 olup prototip düzeyindeki sistem için kabul edilebilir bir aralık göstermektedir.

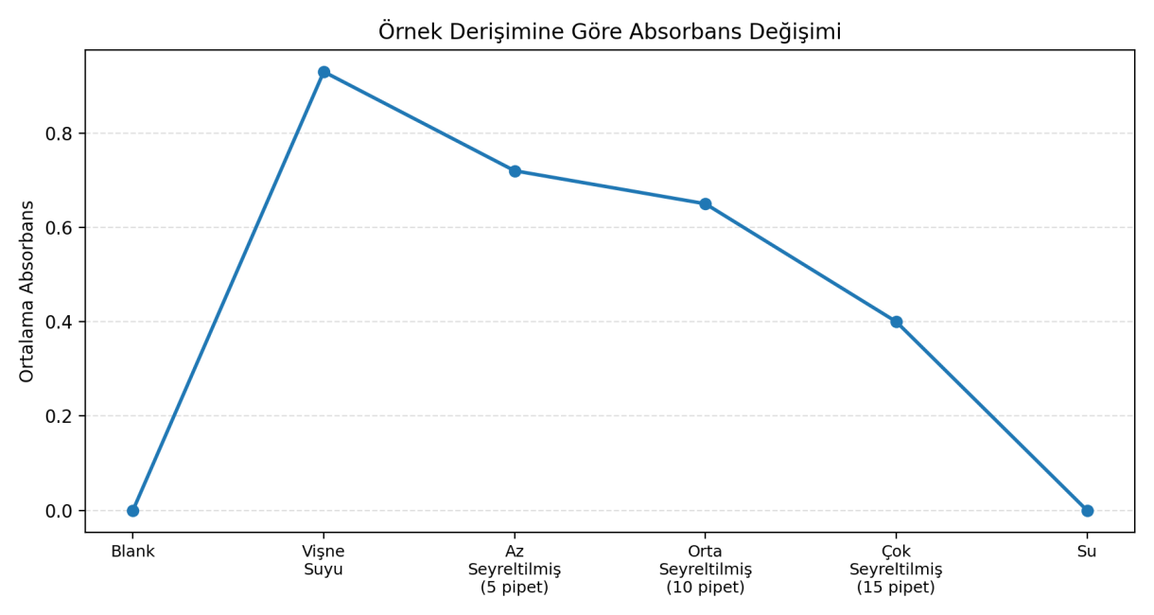
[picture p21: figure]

Şekil 3. Örnek derişimine göre absorbans değişimi.

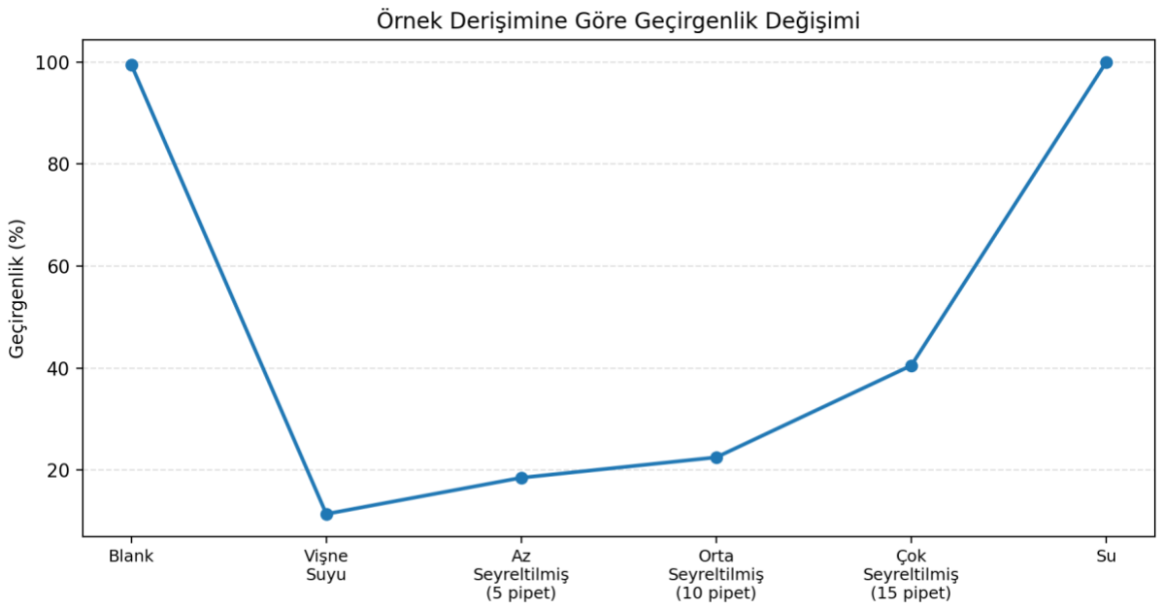
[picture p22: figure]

Şekil 4. Örnek derişimine göre geçirgenlik değişimi.

## 9. Bugünkü Sonuçların Doğruluk Yorumlaması

Deney sonuçlarının en güçlü tarafı, fiziksel olarak beklenen eğilimi vermesidir. Seyreltilmemiş vişne suyu en yüksek absorbansı üretmiş; örneğe su eklendikçe sensöre daha fazla ışık ulaşmış, geçirgenlik yükselmiş ve absorbans kademeli olarak azalmıştır.

Bu durum, sistemin yalnızca örnek var / yok ayrımı yapmadığını; aynı zamanda derişim değişimini de izleyebildiğini göstermektedir. Yani prototip, göreli optik ölçüm açısından anlamlı bir çıktı üretmektedir.

Bununla birlikte bu doğruluk, laboratuvar tipi mutlak cihaz doğruluğu olarak değerlendirilmemelidir. Kullanılan modül profesyonel fotodedektör değildir; ışık kaynağı, optik hizalama ve ADC çözünürlüğü de prototip seviyesindedir. Bu nedenle en güvenli ifade, 'ölçüm eğilimi doğru ve sonuçlar prototip düzeyinde güvenilir' şeklindedir.

Bugün net olarak doğrulananlar | Hâlâ geliştirilmesi gerekenler
- Dark ve blank referansları çalışıyor. | • Daha hassas fotodedektör ile doğruluk artırılabilir.
- Blankte absorbans sıfıra çok yakın. | • Işık kaynağı sabit akım ile sürülmeli.
- Vişne suyunda seyrelme arttıkça absorbans düşüyor. | • Dalga boyu seçimi daha kontrollü hale getirilebilir.
- Saf su blanke yakın davranıyor. | • Küvet geometrisi ve optik hizalama mekanik olarak sabitlenmeli.
- Tekrarlı ölçümler genel eğilimi koruyor. | • Referans laboratuvar cihazı ile karşılaştırmalı kalibrasyon yapılmalı.

## 10. Şu Anda Tam Olarak Ne Durumdayız?

Bugünkü noktada geliştirilen sistem, temel spektrofotometre mantığıyla çalışan düşük maliyetli bir prototip olarak tanımlanabilir. Işık kaynağı, örnek ve dedektör zinciri kurulmuş; referans ölçümler alınmış; örnekten geçen ışık bilgisi kullanılarak transmittance ve absorbance değerleri hesaplanmıştır.

Bu nedenle 'çalışıyor mu?' sorusuna verilecek teknik cevap evettir. Ancak 'laboratuvar tipi hassas bir cihaz mı?' sorusuna verilecek doğru cevap henüz hayırdır. Sistem, prototip ve doğrulama seviyesinde güçlü; ürün ve yüksek hassasiyetli cihaz seviyesinde ise gelişmeye açıktır.

Başka bir ifadeyle bu çalışma, bir bitirme projesini geçmiş; çalışan bir proof of concept haline gelmiştir. En önemli kazanım, düşük maliyetli bir yapıyla optik ölçüm fikrinin pratikte gösterilmiş ve deneysel olarak savunulabilir hâle getirilmiş olmasıdır.

Seviye | Açıklama | Bugünkü karşılığı
Bitirme projesi seviyesi | Çalışan sistem ve raporlanabilir sonuç | Karşılanıyor
Prototip seviyesi | Fikrin deneysel olarak doğrulanması | Karşılanıyor
Araştırma / geliştirme seviyesi | Bir üst donanım sürümüne geçiş için temel | Karşılanıyor
Ticarileşmiş cihaz seviyesi | Yüksek kararlılık, kalibrasyon ve standardizasyon | Henüz değil

## 11. Bu Fikir Neden Küçümsenmemeli?

Dışarıdan bakıldığında Arduino, kablo ve basit sensör kullanıldığı için proje kolaymış gibi görünebilir. Oysa sistemin gerçek teknik değeri; sensör davranışının çözümlenmesi, analog-dijital ayrımının yapılması, referanslı matematik modelin kurulması, hata ayıklama, mekanik yerleşim ve deneysel doğrulama basamaklarının birlikte yürütülmesidir.

Bu çalışma, hazır bir modülü bağlayıp rastgele sayı okumaktan ibaret değildir. Tam tersine; yanlış formüllerin elenmesi, sensörün ters karakteristiğinin anlaşılması ve blank / dark kalibrasyonu üzerinden fiziksel açıdan anlamlı sonuç üretmeye ulaşılması, gerçek mühendislik kararları içermektedir.

Prototipin değeri, pahalı laboratuvar cihazını birebir taklit etmesinden değil; düşük maliyetle aynı fiziksel prensibi anlaşılır, geliştirilebilir ve ölçülebilir şekilde ortaya koyabilmesinden gelir.

## 12. Tez, TÜBİTAK ve Teknofest İçin Potansiyel

Başvuru türü | Bu proje için güçlü taraf | Eksik kalan taraf | Önerilen sonraki adım
Tez / bitirme raporu | Çalışan prototip, referans testleri ve deneysel sonuçlar var | Daha fazla örnek ve karşılaştırmalı veri gerekli olabilir | Farklı sıvılarla seri ölçüm ve kalibrasyon eklemek
TÜBİTAK araştırma projesi | Düşük maliyetli alternatif cihaz fikri güçlü | Bilimsel karşılaştırma ve doğruluk çalışması genişletilmeli | Referans cihazla paralel ölçüm, hata analizi ve istatistik
Teknofest / proje yarışması | Toplumsal erişilebilirlik ve maliyet avantajı dikkat çekici | Donanım paketi ve arayüz daha etkileyici hale getirilmeli | Yeni dedektör, veri kayıt arayüzü ve modüler ışık kaynağı
Ürünleşme fikri | Eğitim laboratuvarları için potansiyel var | Stabilite, güvenilirlik ve kalibrasyon eksik | 2. nesil donanım ve saha testi

Kritik nokta şudur: Bu proje şu haliyle doğrudan ticari cihaz değildir; ancak doğru bir ikinci sürüm planı ile ciddi bir araştırma / yarışma dosyasına dönüşebilecek çekirdek bir platformdur.

## 13. Teknik Olarak En Mantıklı Sonraki Sürüm

Bileşen / konu | Bugünkü yapı | Önerilen yükseltme
Dedektör | LM393 tabanlı AO/DO modül | Gerçek PIN fotodiyot (ör. BPW34 / SFH 203 P) + transimpedans yükselteç
Işık kaynağı | Yeşil ışık kaynağı, temel sürüş | Sabit akım sürücülü belirli tepe dalga boyuna sahip LED
Optik yol | Kısa mesafe, kapalı kutu | Daha iyi hizalama, dar açıklık ve iç yüzey yalıtımı
Elektronik okuma | Arduino Uno dahili ADC | Gerekirse harici ADC veya daha hassas analog ön kat
Yazılım | Dark/blank referanslı temel algoritma | Veri kaydı, grafikleme, otomatik kalibrasyon ve raporlama

## 14. Sonuç

Bu belge kapsamında özetlenen tüm bulgular birlikte değerlendirildiğinde, geliştirilen sistemin temel spektrofotometre mantığıyla çalışan düşük maliyetli bir prototip olduğu açık biçimde görülmektedir.

Proje; nereden başlandığını, hangi teknik sorunların çözüldüğünü, hangi referansların belirlendiğini ve hangi deneysel sonuçların elde edildiğini izlenebilir biçimde ortaya koymaktadır. Bugünkü vişne suyu deneyleri ise prototipin derişim değişimini algılayabildiğini somut olarak doğrulamıştır.

Sonuç olarak bu çalışma ne boşuna yapılmış bir deneme ne de yalnızca rapor doldurmak için hazırlanmış yüzeysel bir düzendir. Doğru geliştirildiğinde tez genişletmesine, araştırma projesine ve yarışma başvurusuna dönüşebilecek kadar güçlü bir teknik çekirdeğe sahiptir.

## Ek A. Hızlı Sonuç Özeti

Test / örnek | Özet sonuç | Tek cümlelik yorum
Dark | Raw ≈ 1023, A ≈ 4.0000 | Karanlık referansı doğru kurulmuş.
Blank | Raw ≈ 194–210, A ≈ 0 | Referans ışık geçişi fiziksel olarak doğru yorumlanıyor.
Vişne suyu | A ≈ 0.93 | En yüksek soğurma yoğun örnekte görüldü.
Az seyreltilmiş | A ≈ 0.72 | Seyreltme absorbansı düşürdü.
Orta seyreltilmiş | A ≈ 0.65 | Beklenen eğilim korundu.
Çok seyreltilmiş | A ≈ 0.40 | Blanke yaklaşma eğilimi görüldü.
Saf su | A ≈ 0.00 | Sistem suyu blanke çok yakın yorumladı.

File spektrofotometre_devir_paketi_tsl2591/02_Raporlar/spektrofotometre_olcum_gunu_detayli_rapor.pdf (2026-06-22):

TSL2591 Tabanlı Spektrofotometre Prototipi - Ölçüm Günü Raporu

# SPEKTROFOTOMETRE PROTOTİPİ

## TSL2591 Sensörlü Arduino Sistemi ile Cary 60 Ölçümlerinin Karşılaştırılması

Rapor türü | Laboratuvar ölçüm günü raporu ve teknik analiz
Tarih | 18.05.2026
Proje | Arduino tabanlı düşük maliyetli spektrofotometre prototipi
Işık kaynağı | Yeşil LED, yaklaşık 550 nm bandı
Sensör | TSL2591 dijital ışık sensörü
Referans cihaz | Cary 60 UV-Vis Spektrofotometre, 550 nm

Raporun amacı

Bu rapor, ölçüm günü boyunca gerçekleştirilen numune hazırlama, prototip ölçümü, Cary 60 ölçümü, veri karşılaştırması, hata/eksik analizi ve gelecek geliştirme planlarını tek bir teknik dokümanda toplamaktadır.

### İçindekiler

1. Yönetici Özeti
2. Deneyin Amacı ve Kapsamı
3. Kullanılan Yöntem ve Laboratuvar Süreci
4. Prototip Sistem ve Web Panel
5. Kalibrasyon, Dark ve Kör/Blank Mantığı
6. Ölçüm Verileri
7. Prototip - Cary 60 Karşılaştırmalı Analiz
8. Doğru Çalışan Noktalar
9. Yanlış/Eksik Kalan Noktalar
10. Gelecekte Yapılması Gerekenler
11. Sonuç
12. Görsel Ekler

### Şekiller Listesi

Şekil 1. Prototip ölçümleri - ölçülen ve kör çıkarılmış absorbans

Şekil 2. Prototip grup ortalamaları ve standart sapma

Şekil 3. Prototip ve Cary 60 normalize eğilim karşılaştırması

Şekil 4. Numune bazında Prototip-Cary 60 ilişkisi

Şekil 5. Prototipte Raw Visible ve Transmittance değişimi

Şekil 6. Cary 60 grup ortalamaları

Şekil 7-16. Laboratuvar ve deney günü görselleri

### Tablolar Listesi

Tablo 1. Ölçüm günü numune grupları

Tablo 2. Prototip ölçüm sonuçları

Tablo 3. Grup ortalamaları

Tablo 4. Cary 60 eşleştirme tablosu

Tablo 5. Prototip-Cary karşılaştırması ve yorum

Tablo 6. Sorunlar, etkileri ve çözüm önerileri

### 1. Yönetici Özeti

18.05.2026 tarihinde düşük maliyetli spektrofotometre prototipi gerçek laboratuvar koşullarında denenmiştir. Çalışmada kondanse tanen yöntemi kapsamında farklı tanen miktarları ile hazırlanan çözeltiler hem Cary 60 UV-Vis spektrofotometrede hem de Arduino-TSL2591 tabanlı prototipte ölçülmüştür.

Prototip sistemde yeşil LED yaklaşık 550 nm bandında ışık kaynağı olarak kullanılmış, TSL2591 sensörü ise numuneden geçen görünür ışığı ölçmüştür. Web panel üzerinden Raw Visible, Transmittance, Absorbance ve Average Absorbance değerleri canlı olarak izlenmiştir.

Temel sonuç olumlu yöndedir: tanen miktarı arttıkça prototipte Raw Visible değeri genel olarak düşmüş, Transmittance azalmış ve absorbans yükselmiştir. Bu durum, prototipin spektrofotometre prensibini algıladığını ve numuneler arasında yoğunluk farkı ayırt edebildiğini göstermektedir.

Bununla birlikte prototip ölçümleri profesyonel Cary 60 cihazı ile birebir aynı çıkmamıştır. Bu beklenen bir durumdur; çünkü Cary 60 monokromatik ve kalibre edilmiş bir laboratuvar cihazıdır, prototip ise geniş bant yeşil LED, manuel hizalama ve düşük maliyetli optik düzenek kullanmaktadır.

Ana bulgu

Prototip grup ortalamaları 0,002 g grubunda 0,8757 iken 0,010 g grubunda 1,9508 değerine yükselmiştir. Tam aralıkta grup ortalamasına göre yaklaşık R² = 0.81, ilk üç grup için R² = 0.91 hesaplanmıştır. Bu, özellikle düşük-orta aralıkta prototipin düzenli eğilim verdiğini gösterir.

### 2. Deneyin Amacı ve Kapsamı

Bu çalışmanın ana amacı, prototip spektrofotometrenin yalnızca teorik olarak değil, gerçek laboratuvar örnekleri üzerinde de ölçüm yapabildiğini göstermektir. Bu nedenle deney günü hem numune hazırlama süreci hem de cihaz karşılaştırması birlikte yürütülmüştür.

Proje açısından kritik değerlendirme noktaları şunlardır: (1) sensör-ışık-küvet hizasının ölçüm üretip üretmediği,
(2) yeni 3D baskı kutunun ortam ışığını yeterince engelleyip engellemediği, (3) web panelin canlı veri takibi için kullanılabilirliği, (4) prototip sonuçlarının Cary 60 ile aynı eğilimi gösterip göstermediği ve (5) hangi geliştirmelerin zorunlu olduğudur.

Bu raporda ölçümlerin mutlak cihaz eşdeğerliği değil, prototipin trend yakalama yeteneği öne alınmıştır. Çünkü prototip sistemi henüz ticari bir spektrofotometre yerine geçecek seviyede kalibre edilmiş değildir; ancak düşük maliyetli bir öğretim/araştırma prototipi olarak bilimsel davranışı izleyebilmelidir.

Tablo 1. Ölçüm günü kullanılan numune grupları ve tartım değerleri

Grup | Örnekler | Tartım değerleri | Not
0,002 g | 1-2-3 | 0,0020 / 0,0024 / 0,0025 g | 3 numaralı tüp kırıldığı için ölçülemedi
0,004 g | 4-5-6 | 0,0048 / 0,0040 / 0,0042 g | Ölçüldü
0,006 g | 7-8-9 | 0,0066 / 0,0063 / 0,0068 g | Ölçüldü
0,008 g | 10-11-12 | 0,0088 / 0,0088 / 0,0081 g | Ölçüldü
0,010 g | 13-14-15 | 0,0125 / 0,0106 / 0,0107 g | Ölçüldü

### 3. Kullanılan Yöntem ve Laboratuvar Süreci

Çalışma, kondanse tanen tayini için kullanılan HCl-bütanol yöntemi temel alınarak yürütülmüştür. Metodun temel mantığı, tanenlerin asidik butanol ortamında renkli kompleks oluşturması ve oluşan rengin 550 nm civarında absorbansla takip edilmesidir.

Laboratuvar sürecinde örnekler tartılmış, HCl-bütanol çözeltisi hazırlanmış, tüpler kapatılarak ısıtma/reaksiyon aşamasına alınmış ve renk gelişimi gözlenmiştir. Kırmızı-koyu renk oluşumu, tanen içeriği ve reaksiyon ilerlemesi hakkında görsel bir işaret sağlamıştır.

Ölçüm öncesinde tüpler soğutulmuş ve ölçüme uygun hacim alınarak küvet/prototip ölçüm bölgesinde değerlendirilmiştir. Profesyonel cihazda Cary 60 ile 550 nm ölçüm yapılmış; prototipte ise yeşil LED ışığı ve TSL2591 görünür kanal değeri kullanılmıştır.

Metot notu

Cary 60 cihazı 550 nm dalga boyunu doğrudan seçer. Prototip ise yeşil LED kullandığı için ölçüm bandı yaklaşık 550 nm civarındadır; bu nedenle mutlak değerlerin aynı çıkması beklenmez, ancak eğilimin aynı yönde olması beklenir.

### 4. Prototip Sistem ve Web Panel

Prototip sistem Arduino Uno, TSL2591 dijital ışık sensörü, yeşil LED, siyah 3D baskı kutu, küvet yuvası ve Python/Flask tabanlı canlı web panelden oluşmaktadır. Siyah kutu ışık sızıntısını azaltmak ve sensör-ışık-küvet hizasını sabitlemek için kullanılmıştır.

Web panel ölçüm sırasında cihazı izlemek açısından önemli bir yenilik sağlamıştır. Panelde Raw Visible, Transmittance, Absorbance ve Average Absorbance kartları; canlı Chart.js grafikleri; örnek adı seçimi; tablo temizleme; CSV/Excel indirme altyapısı yer almaktadır.

Bugünkü çalışmada panelin canlı değerleri doğru şekilde gösterdiği görülmüştür. Ancak bazı ekranlarda kayıt durumunun pasif kaldığı ve örnek adının değişmediği görülmüştür. Bu durum, kullanıcı akışında otomatik örnek sırası ve kayıt doğrulaması eklenmesi gerektiğini göstermiştir.

### 4.1. Prototip hesaplama mantığı

I_blank = blankRaw - darkRaw

I_sample = rawValue - darkRaw

Transmittance = I_sample / I_blank

Absorbance = -log10(Transmittance)

Düzeltilmiş Absorbance = Numune Average Absorbance - Kör Average Absorbance

### 5. Kalibrasyon, Dark ve Kör/Blank Mantığı

Profesyonel spektrofotometrelerde blank/kör çözeltisi ile Zero işlemi yapılır. Cihaz bu çözeltiyi 0 absorbans kabul eder ve sonraki numunelerde blank etkisini otomatik olarak düşer.

Prototipte ise ölçüm sırasında kodda daha önce kullanılan blankRaw değeri 965 olarak kalmıştır. Bugünkü gerçek kör ölçümünde Raw Visible yaklaşık 379,70 ve Average Absorbance yaklaşık 0,4056 olarak gözlenmiştir. Bu nedenle prototipte kör ölçümü sıfır çıkmamıştır.

Bu durum tüm ölçümleri geçersiz yapmaz; çünkü tüm numuneler aynı referans koşulunda ölçülmüştür. Analizde Cary 60 cihazındaki Zero işleminin karşılığı olarak prototip değerlerinden kör absorbansı çıkarılmıştır.

Kritik düzeltme

Bu raporda prototip için kör düzeltmesi 0,4056 değeri ile yapılmıştır. Yani her numunenin Average Absorbance değerinden 0,4056 çıkarılmıştır.

### 6. Ölçüm Verileri

Bu bölümde prototip ve Cary 60 cihazından elde edilen ölçüm verileri bir arada sunulmuştur. Prototip verileri ekran görüntülerindeki stabil ortalama değerlerden derlenmiştir; CSV dosyası üzerinden tekrar kontrol edilirse değerler daha hassas hale getirilebilir.

Tablo 2. Prototip ölçüm sonuçları ve kör çıkarılmış absorbans değerleri

No | Grup | Tartım (g) | Raw | T (%) | Avg Abs | Düzeltilmiş Abs | Not
Kör | — | — | 379,70 | 39,30 | 0,4056 | 0,0000 | Kör/blank referansı
1 | 0,002 g | 0,0020 | 55,70 | 5,70 | 1,2439 | 0,8383
2 | 0,002 g | 0,0024 | 47,00 | 4,80 | 1,3186 | 0,9130
3 | 0,002 g | 0,0025 | — | — | — | — | Ölçüm öncesi kırıldı
4 | 0,004 g | 0,0048 | 9,00 | 0,86 | 2,0651 | 1,6595
5 | 0,004 g | 0,0040 | 12,00 | 1,17 | 1,9311 | 1,5255
6 | 0,004 g | 0,0042 | 12,90 | 1,27 | 1,8980 | 1,4924
7 | 0,006 g | 0,0066 | 11,00 | 1,07 | 1,9714 | 1,5658
8 | 0,006 g | 0,0063 | 6,00 | 0,55 | 2,2599 | 1,8543
9 | 0,006 g | 0,0068 | 5,80 | 0,53 | 2,2781 | 1,8725
10 | 0,008 g | 0,0088 | 6,80 | 0,63 | 2,1999 | 1,7943
11 | 0,008 g | 0,0088 | 5,90 | 0,54 | 2,2690 | 1,8634
12 | 0,008 g | 0,0081 | 5,60 | 0,51 | 2,2963 | 1,8907
13 | 0,010 g | 0,0125 | 5,70 | 0,52 | 2,2872 | 1,8816
14 | 0,010 g | 0,0106 | 4,80 | 0,43 | 2,3737 | 1,9681
15 | 0,010 g | 0,0107 | 4,50 | 0,39 | 2,4082 | 2,0026

Tablo 3. Grup ortalamaları, standart sapma ve referans cihaz karşılaştırması

Grup | n | Ort. tartım (g) | Prototip ort. düzeltilmiş Abs | Prototip SD | Cary 60 ort. Abs | Cary 60 SD | Yorum
0,002 g | 2 | 0,0022 | 0,8757 | 0,0528 | 2,7653 | 0,1264 | İki tekrar; 3. tüp kırıldı
0,004 g | 3 | 0,0043 | 1,5591 | 0,0885 | 3,5900 | 0,1102 | Belirgin artış
0,006 g | 3 | 0,0066 | 1,7642 | 0,1721 | 3,6165 | 0,0606 | Yüksek absorbans bölgesine geçiş
0,008 g | 3 | 0,0086 | 1,8495 | 0,0497 | 3,6572 | 0,1223 | Plato etkisi başladı
0,010 g | 3 | 0,0113 | 1,9508 | 0,0623 | 3,4818 | 0,0874 | En yüksek grup; prototipte artış sürüyor

### 7. Prototip - Cary 60 Karşılaştırmalı Analiz

Prototip ve Cary 60 arasında mutlak değer farkı vardır. Bu farkın ana sebepleri optik kaynak, dedektör hassasiyeti, dalga boyu seçiciliği, blank alma yöntemi ve numune-ışık geometrisidir.

Prototip için en güçlü gösterge, grup ortalamalarının genel olarak artmasıdır. Bu, sistemin konsantrasyon/renk yoğunluğu farkına duyarlı olduğunu gösterir. Cary 60 cihazında ise absorbanslar 3,4 -3,7 gibi oldukça yüksek bir aralıkta yoğunlaşmıştır. Bu durum çözeltilerin çok güçlü absorbans verdiğini ve lineer aralığın zorlandığını düşündürür.

Prototip grup ortalamaları ile nominal tanen grubu arasında tam aralıkta yaklaşık R² = 0.81 bulunmuştur. İlk üç grup dikkate alındığında R² yaklaşık 0.91 seviyesine yükselmektedir. Bu sonuç yüksek konsantrasyonlarda plato/sensör sınırı etkisinin arttığını gösterir.

Numune bazında prototip düzeltilmiş absorbansı ile Cary 60 absorbansı arasındaki Pearson korelasyonu yaklaşık r = 0.81 olarak hesaplanmıştır. Bu değer, iki sistemin tamamen aynı ölçmediğini ancak belirli bir ortak eğilim taşıdığını gösterir.

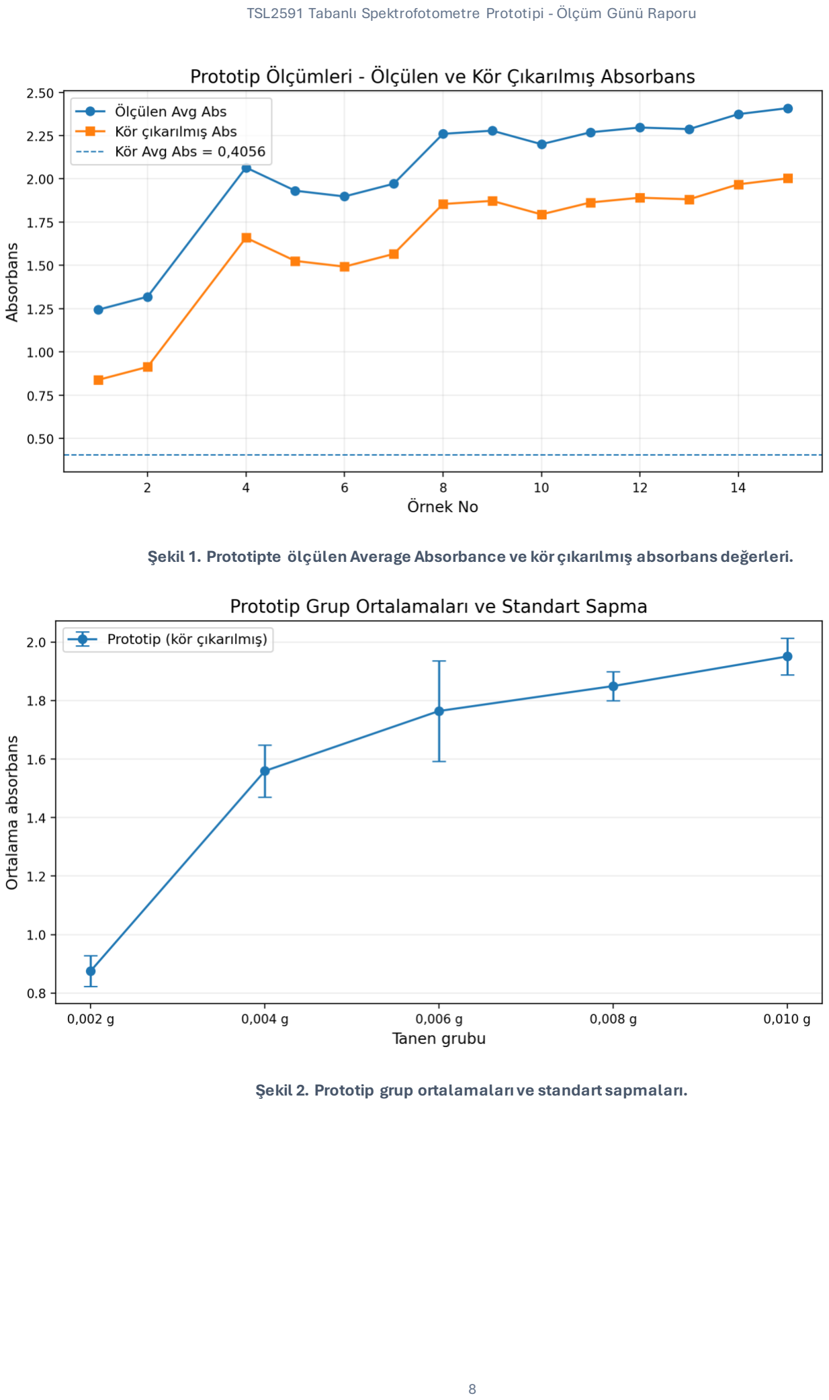
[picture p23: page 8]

Şekil 1. Prototipte ölçülen Average Absorbance ve kör çıkarılmış absorbans değerleri.

Şekil 2. Prototip grup ortalamaları ve standart sapmaları.

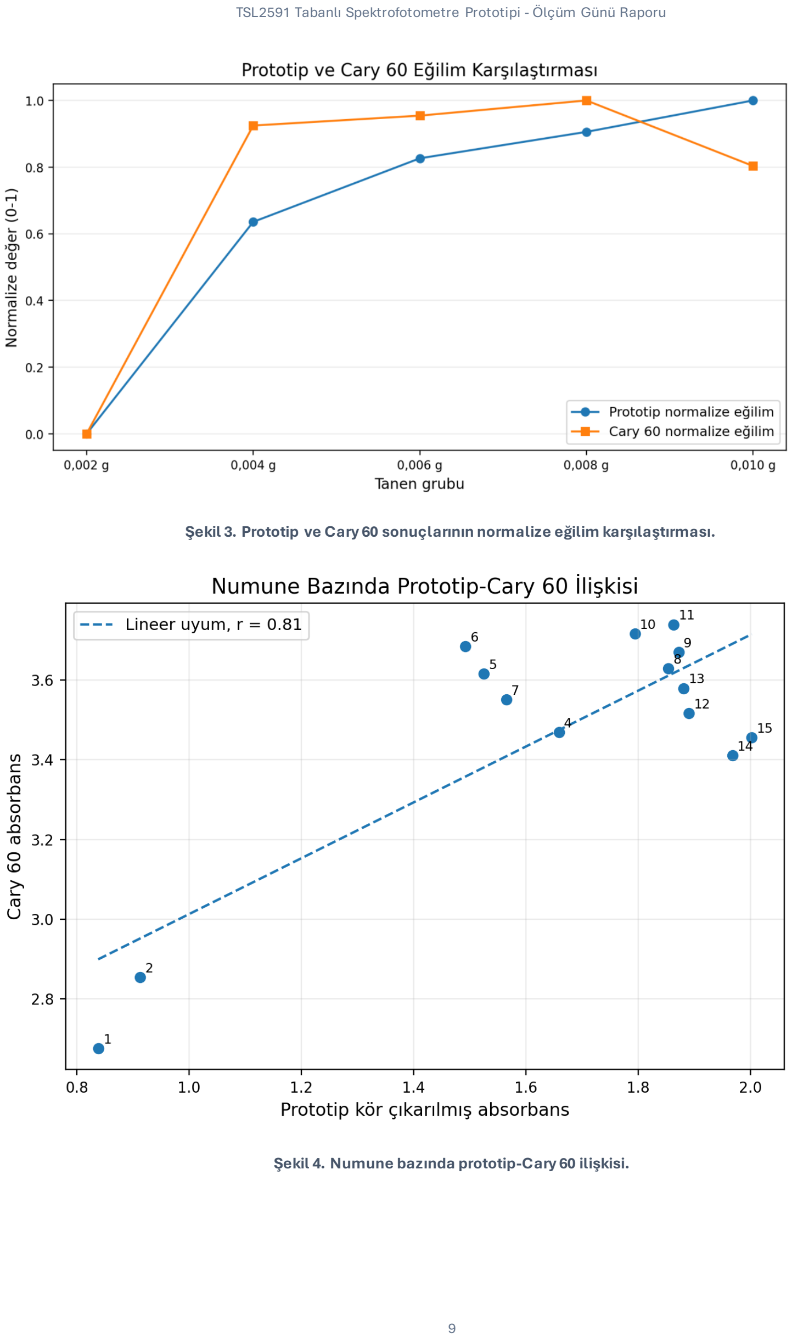
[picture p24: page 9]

Şekil 3. Prototip ve Cary 60 sonuçlarının normalize eğilim karşılaştırması.

Şekil 4. Numune bazında prototip-Cary 60 ilişkisi.

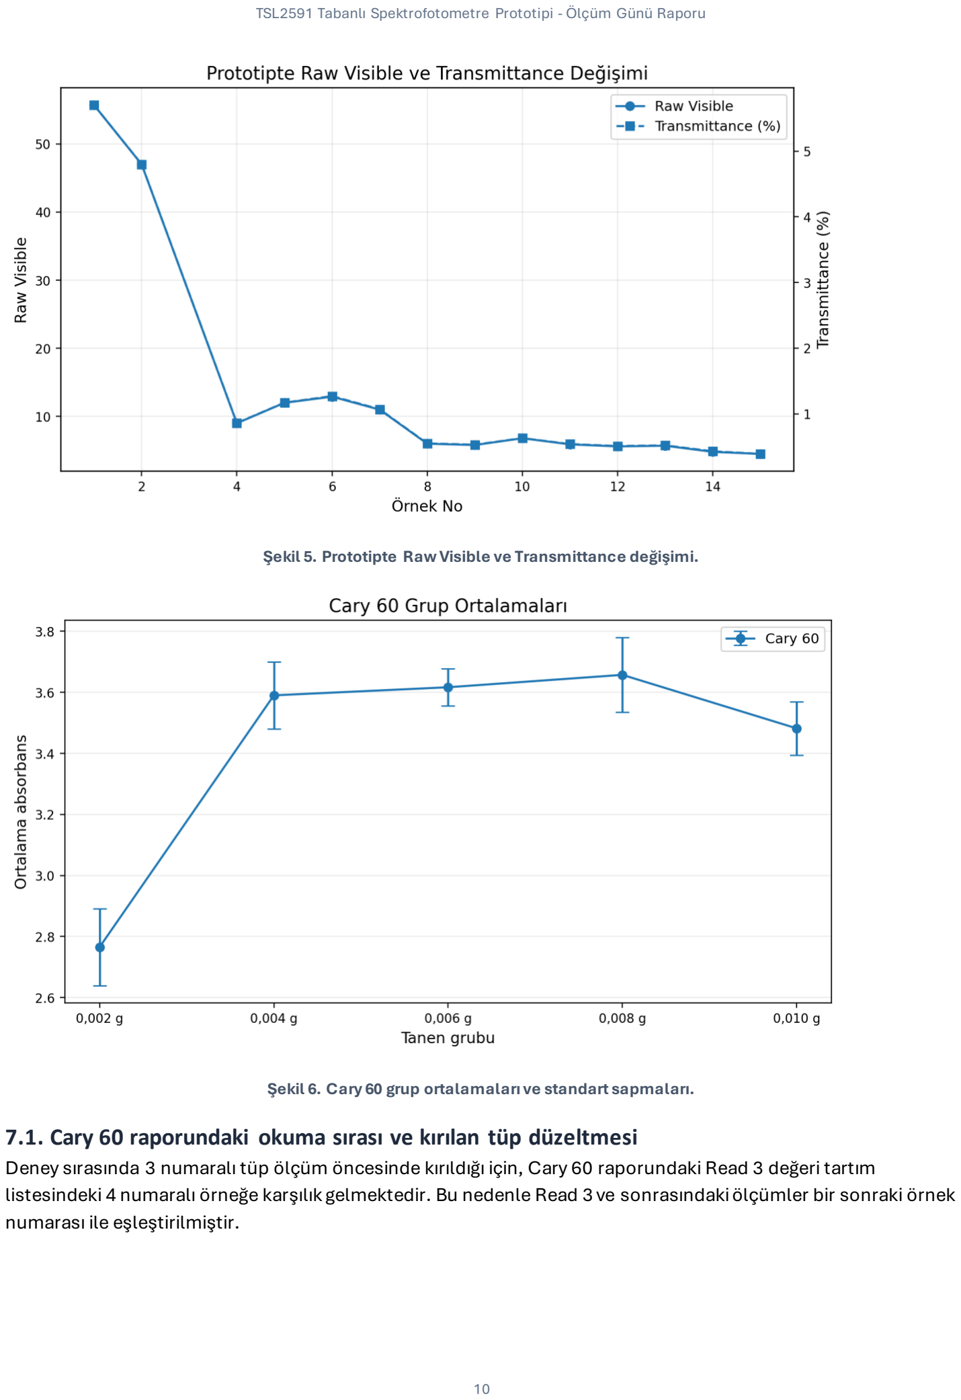
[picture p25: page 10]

Şekil 5. Prototipte Raw Visible ve Transmittance değişimi.

Şekil 6. Cary 60 grup ortalamaları ve standart sapmaları.

### 7.1. Cary 60 raporundaki okuma sırası ve kırılan tüp düzeltmesi

Deney sırasında 3 numaralı tüp ölçüm öncesinde kırıldığı için, Cary 60 raporundaki Read 3 değeri tartım listesindeki 4 numaralı örneğe karşılık gelmektedir. Bu nedenle Read 3 ve sonrasındaki ölçümler bir sonraki örnek numarası ile eşleştirilmiştir.

Tablo 4. Cary 60 okuma sırası ile gerçek örnek numarası eşleştirmesi

Cary Read | Gerçek örnek no | Tartım (g) | Cary 60 Abs | Not
Read 1 | 1 | 0,0020 | 2,6759 | Ölçüldü
Read 2 | 2 | 0,0024 | 2,8547 | Ölçüldü
— | 3 | 0,0025 | — | Ölçüm öncesi kırıldı
Read 3 | 4 | 0,0048 | 3,4692 | Ölçüldü
Read 4 | 5 | 0,0040 | 3,6160 | Ölçüldü
Read 5 | 6 | 0,0042 | 3,6849 | Ölçüldü
Read 6 | 7 | 0,0066 | 3,5507 | Ölçüldü
Read 7 | 8 | 0,0063 | 3,6289 | Ölçüldü
Read 8 | 9 | 0,0068 | 3,6700 | Ölçüldü
Read 9 | 10 | 0,0088 | 3,7156 | Ölçüldü
Read 10 | 11 | 0,0088 | 3,7393 | Ölçüldü
Read 11 | 12 | 0,0081 | 3,5166 | Ölçüldü
Read 12 | 13 | 0,0125 | 3,5793 | Ölçüldü
Read 13 | 14 | 0,0106 | 3,4106 | Ölçüldü
Read 14 | 15 | 0,0107 | 3,4556 | Ölçüldü

### 8. Doğru Çalışan Noktalar

Kutu ve dark kontrolü: Işık kapalı ve kutu kapalı durumda Raw Visible değerinin yaklaşık 0,7 civarında olması, kutunun dış ortam ışığını büyük ölçüde kestiğini gösterir.

Sensör tepkisi: Kör çözeltiden koyu numunelere geçildiğinde Raw Visible değerleri çok belirgin şekilde düşmüş ve absorbans artmıştır.

Trend algılama: 0,002 g grubundan 0,010 g grubuna doğru prototipin kör çıkarılmış grup ortalamaları genel olarak artmıştır.

Web panel kullanılabilirliği: Canlı grafik, ölçüm kartları ve tablo sistemi ölçüm sırasında anlık kontrol sağlamıştır.

Cary 60 ile karşılaştırma olanağı: Prototip verileri aynı numuneler için profesyonel cihazla karşılaştırılabilir bir analiz seti üretmiştir.

### 9. Yanlış, Eksik veya Sınırlı Kalan Noktalar

Tablo 5. Gözlenen sorunlar, etkileri ve önerilen çözümler

Sorun / sınırlılık | Ölçüme etkisi | Önerilen çözüm
blankRaw eski değerle kaldı | Kör ölçümü 0 absorbans yerine yaklaşık 0,4056 çıktı | Web panelde otomatik Blank Al / Zero Yap butonu eklenmeli
Örnek adı bazı ekranlarda Kör / Blank kaldı | CSV kayıtları yanlış isimlenebilir veya kayıt pasif kalabilir | Ölçüm sırası otomatikleştirilmeli, kayıt başlamadan örnek adı doğrulanmalı
3 numaralı tüp kırıldı | 0,002 g grubunda tekrar sayısı azaldı | Tekrar sayısı artırılmalı ve yedek tüp hazırlanmalı
Yüksek absorbans bölgesinde Raw çok düştü | 4-6 Raw seviyelerinde gürültü/hizalama etkisi büyür | Numuneler seyreltilmeli veya ışık/optik yapı optimize edilmeli
LED monokromatik değil | Cary 60 ile mutlak değer farkı oluşur | 550 nm dar bant optik filtre veya daha seçici LED kullanılmalı

Özellikle yüksek absorbans bölgesinde prototipin Raw Visible değerleri çok düşük seviyelere inmiştir. Bu durum sistemin numuneleri ayırt ettiğini gösterse de aynı zamanda duyarlılık sınırına yaklaşıldığını da gösterir.

Cary 60 cihazında da ölçümlerin 3 absorbans biriminin üzerine çıkması, çözeltilerin oldukça koyu olduğunu ve daha seyreltik ölçüm serisinin daha güvenilir olabileceğini düşündürmektedir. Gelecek ölçümlerde tüm numuneler lineer aralığa daha yakın olacak şekilde seyreltilebilir.

Prototip verilerinin bugün ekran görüntülerinden derlenmiş olması rapor için yeterli bir ön analiz sağlar; ancak final akademik raporda CSV dosyası üzerinden satır satır ortalama ve standart sapma hesaplanması daha güçlü olacaktır.

### 10. Gelecekte Yapılması Gerekenler

### 10.1. Otomatik blank/zero sistemi

Panelde Blank Al / Zero Yap butonu eklenmelidir. Kullanıcı kör çözeltisini yerleştirip bu butona bastığında sistem o anki Raw Visible değerini referans olarak almalı ve tüm absorbansları buna göre hesaplamalıdır.

### 10.2. Otomatik örnek sırası ve kayıt güvenliği

Panelde ölçüm listesi önceden tanımlanmalı, her örnek için Başlat-Durdur akışı otomatik ilerlemeli ve kayıt pasifken veri alınması kullanıcıya belirgin şekilde bildirilmeli veya engellenmelidir.

### 10.3. Kalibrasyon modeli

Cary 60 değerleri referans alınarak Prototip-Cary dönüşüm modeli kurulabilir. Örneğin Cary Abs = a x Prototip Abs + b şeklinde bir lineer model veya yüksek absorbans bölgesi için daha uygun bir eğri kullanılabilir.

### 10.4. Optik iyileştirme

LED sabit akım sürücü ile beslenmeli, 550 nm dar bant filtre eklenmeli, ışık yolu kolime edilmeli, küvet yuvası tek yönlü ve sabit stoplu hale getirilmelidir.

### 10.5. Seyreltme ve lineer aralık

Koyu numuneler ölçüm aralığını zorladığı için yeni deneyde tüm numuneler daha seyreltik hazırlanmalı veya ölçüm öncesi uygun seyreltme katsayısı belirlenmelidir.

### 10.6. İstatistik ve otomatik raporlama

Her grup için ortalama, standart sapma, varyasyon katsayısı, R², kör çıkarılmış absorbans ve grafikler panelden otomatik alınmalı; CSV yanında Word/PDF rapor çıktısı üretilmelidir.

### 10.7. Donanım güvenilirliği

Kablolar daha kısa ve sabitlenmiş olmalı, Arduino ve sensör kutu üzerinde mekanik olarak korunmalı, USB/serial port hataları için yazılımda otomatik yeniden bağlanma/uyarı sistemi güçlendirilmelidir.

### 11. Sonuç

Bugünkü ölçüm günü, prototipin gerçek laboratuvar koşullarında çalışabildiğini ve spektrofotometrik prensibe uygun yönde veri üretebildiğini göstermiştir. Prototipin temel başarısı, numune koyulaştıkça ışık geçirgenliğini düşürmesi ve absorbansı yükseltmesidir.

Prototip ile Cary 60 arasında mutlak değer farkı bulunması normaldir. Çünkü iki sistemin optik yapısı, dalga boyu seçiciliği, dedektör hassasiyeti ve blank düzeltme yöntemi farklıdır. Buna rağmen prototip, grup ortalamalarında artış eğilimi vermiş ve numune yoğunluğu değişimini algılamıştır.

Bu sonuçlar, prototipin öğretim, düşük maliyetli ön analiz ve proje geliştirme açısından başarılı bir temel oluşturduğunu göstermektedir. Bir sonraki aşamada otomatik blank alma, kalibrasyon modeli, optik filtre, sabit küvet yuvası ve seyreltilmiş ölçüm serisi ile sistemin doğruluğu belirgin biçimde artırılabilir.

Genel karar

Prototip başarılı bir doğrulama günü geçirmiştir. Sistem profesyonel cihazın yerini doğrudan alacak seviyede değildir; ancak spektrofotometre prensibini uygulayan, canlı veri sunan ve geliştirilebilir bir düşük maliyetli ölçüm platformu olarak güçlü bir sonuç vermiştir.

### 12. Görsel Ekler - Deney Günü Fotoğrafları

Bu bölümde deney günü boyunca alınan görseller belge niteliğinde sunulmuştur. Görseller, numune hazırlama, ısıtma, renk gelişimi, prototip düzeneği ve laboratuvar ortamını göstermektedir.


Şekil 7. Laboratuvar genel hazırlık alanı, reaktifler ve ısıtıcı-karıştırıcı düzeneği.


Şekil 8. Çalışmanın yürütüldüğü laboratuvar ortamı ve tezgah düzeni.

Şekil 9. Arduino tabanlı prototip, siyah 3D baskı kutu ve hazırlanmış numune dizisi.


Şekil 10. Mikroplaka üzerinde numune aktarımı ve renklenme gözlemi.

Şekil 11. Tüplerin ölçüm öncesi düzenlenmesi ve numune hazırlık aşaması.


Şekil 12. Isıtma sürecinde açık renkli çözelti grubunun görünümü.

Şekil 13. Isıtma sürecinde çözelti rengi ve sıcaklık/karıştırma kontrolü.


Şekil 14. Daha ileri ısıtma aşamasında çözelti grubu ve cihaz göstergesi.

Şekil 15. Tanen kompleksi oluşumu sonrası kırmızı-koyu renkli çözelti grubu.


Şekil 16. Reaksiyon sonrası koyu renkli tüpler ve soğutma/hazırlık aşaması.

### Ek Notlar

Bu rapordaki prototip verileri ölçüm ekranındaki son stabil değerler üzerinden hazırlanmıştır. CSV/Excel kaydı mevcutsa final raporda aynı analiz CSV verisiyle tekrar hesaplanmalıdır.

3 numaralı tüp kırıldığı için hem prototip hem Cary 60 eşleştirmesinde bu örnek eksik bırakılmıştır. Cary 60 raporundaki Read 3 değeri gerçek örnek no 4 olarak değerlendirilmiştir.

Gelecek ölçüm gününde en kritik adım prototipte ölçümden hemen önce gerçek kör çözeltisiyle otomatik zero yapılmasıdır.

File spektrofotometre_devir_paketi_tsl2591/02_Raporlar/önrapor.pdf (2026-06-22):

# Çalışma Raporu Arduino Tabanlı Spektrofotometre Prototipi

Proje konusu

Düşük maliyetli, Arduino tabanlı spektrofotometre prototipinin geliştirilmesi ve temel optik doğrulama testlerinin yapılması
Rapor kapsamı | Sistem kurulumu, kalibrasyon mantığı, uygulanan testler, gözlemler ve elde edilen sonuçların özeti

### 1. Projenin amacı

Bu çalışmanın amacı, düşük maliyetli bileşenler kullanılarak çalışan bir spektrofotometre prototipi oluşturmak ve sistemin temel optik ölçüm mantığını doğrulamaktır. Projede ışık kaynağı, örnek küveti ve algılayıcı sensör aynı optik eksen üzerinde konumlandırılmış; Arduino UNO ile analog veri okunarak geçirgenlik ve absorbans hesaplanmıştır.

Çalışmada öncelik, laboratuvar düzeyi mutlak hassasiyet elde etmekten ziyade, spektrofotometrenin temel prensiplerini doğru şekilde uygulayan, tekrarlanabilir ve anlaşılır bir prototip geliştirmektir.

### 2. Kullanılan sistem ve çalışma prensibi

Sistem; Arduino UNO, analog çıkış veren optik sensör modülü, yeşil ışık kaynağı, küvet yuvası ve ışık sızmasını azaltmak için tasarlanan karanlık kutudan oluşmaktadır. Ölçüm mantığı şu şekildedir: ışık kaynağından çıkan ışık küvet içerisinden geçer, karşı taraftaki sensöre ulaşır ve sensörde oluşan analog değer Arduino tarafından okunur. Numune tarafından daha fazla ışık soğurulduğunda sensöre ulaşan ışık miktarı azalır; buna bağlı olarak geçirgenlik düşer ve absorbans artar.

Kurulum sürecinde sensörün ters mantıklı davrandığı gözlenmiştir. Buna göre daha fazla ışık geldiğinde ham sensör değeri düşmekte, ışık azaldığında ise ham sensör değeri yükselmektedir. Bu nedenle hesaplama kodu, doğrudan 0-1023 aralığını yüzde geçirgenlik gibi kullanmak yerine dark ve blank referanslarına göre düzenlenmiştir.

### 3. Kalibrasyon yaklaşımı

Doğru ölçüme yaklaşmak için üç temel durum tanımlanmıştır: Dark (ışık kapalı / karanlık ölçüm), Blank (ışık açık + boş küvet) ve Sample (ışık açık + numune). Önce sistemin karanlıktaki referansı belirlenmiş, ardından boş küvet kullanılarak blank referansı alınmıştır. Sonrasında numune ölçümlerinde analog ham değer, bu iki referansa göre işlenmiştir.

Kullanılan hesaplama mantığı aşağıdaki gibidir:

I_blank = darkRaw - blankRaw I_sample = darkRaw - rawValue
T = I_sample / I_blank
A = -log10(T)

Burada T geçirgenlik (transmittance), A ise absorbans değeridir. Ölçüm kararlılığını artırmak amacıyla tek okumaya bağlı kalınmamış, birden fazla okumanın ortalaması alınmıştır.

### 4. Uygulanan testler

Prototip üzerinde önce bağlantı doğrulaması yapılmış, ardından sensörün analog çıkışı seri monitör üzerinden gözlemlenmiştir. Sensörün telefon flaşı ve yeşil ışık kaynağına tepki verdiği görülmüş; buna göre sensörün ışık algıladığı doğrulanmıştır. Sonrasında karanlık ölçüm, boş küvet ölçümü ve farklı boş küvetler ile tekrar testleri yapılarak sistemin tekrarlanabilirliği değerlendirilmiştir.

### 5. Test sonuçlarının özeti

Dark ölçümü (Işık kapalı, boş küvet); Sistem tam karanlıkta; maksimum ham değere ulaştı. Dark referansı doğru belirlendi.; Blank ölçümü (Işık açık, boş küvet); Blank ölçümleri yüzde 100 geçirgenliğe ve sıfıra yakın absorbansa ulaştı. Sistem referansı doğru kuruldu.; Tekrar boş küvet testi (Sabit yeşil ışık); Yaklaşık 99 - 100; Yaklaşık 0; İkinci boş küvet ile de; benzer sonuçlar alındı. Sistem tekrarlanabilir görünmektedir.

Test durumu | Ham değer (Raw) | Geçirgenlik (%) | Absorbans | Yorum
194 - 210 | 98.78 - 100.00 | 0.0000 - 0.0053

### 6. Nihai yazılım yaklaşımı

Nihai Arduino kodunda analog ölçüm A0 pininden alınmış; darkRaw ve blankRaw değerleri sabit referans olarak tanımlanmıştır. Ölçüm sırasında okunan ham değer bu referanslara göre işlenmiş, geçirgenlik 0 ile 1 arasında sınırlandırılmış ve absorbans değeri A = -log10(T) formülü ile hesaplanmıştır. Ek olarak sampleCount parametresi ile birden fazla örnekleme yapılarak Average Absorbance değeri üretilmiştir. Raporlamada ve karşılaştırmalarda en güvenilir çıktı olarak Average Absorbance değeri esas alınmıştır.

Testler sonucunda kullanılan referans değerler darkRaw = 1023.0 ve blankRaw = 200.0 olarak kabul edilmiştir. Bu değerler, elde edilen blank sonuçlarının sıfıra yakın absorbans vermesiyle doğrulanmıştır.

### 7. Değerlendirme ve sonuç

Yapılan testler sonucunda sistemin dark ve blank referanslarının kararlı şekilde belirlendiği, boş küvette beklenen şekilde yaklaşık yüzde 100 geçirgenlik ve sıfıra yakın absorbans değerleri ürettiği görülmüştür. Bu durum, prototipin temel spektrofotometrik çalışma mantığını doğru şekilde uyguladığını göstermektedir.

Sonuç olarak, hazırlanan Arduino tabanlı spektrofotometre prototipi test ve gösterim amaçlı kullanıma hazır durumdadır. Mevcut donanımla eğitim ve proje düzeyinde doğru prensiple çalışan, tekrarlanabilir ve anlaşılır bir ölçüm sistemi elde edilmiştir. Bir sonraki aşamada farklı numuneler üzerinde ölçüm alınarak blank referansına göre absorbans değişimleri karşılaştırılacaktır.

Not: Bu rapordaki sayısal sonuçlar, proje geliştirme sürecinde seri monitörde gözlenen test çıktılarından derlenmiştir.

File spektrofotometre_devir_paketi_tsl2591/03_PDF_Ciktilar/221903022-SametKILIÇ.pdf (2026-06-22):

### T.C. MUŞ ALPARSLAN ÜNİVERSİTESİ

UYGULAMALI BİLİMLER FAKÜLTESİ

BİLİŞİM SİSTEMLERİ VE TEKNOLOJİLERİ BÖLÜMÜ

### ARDUINO TABANLI DÜŞÜK MALİYETLİ

SPEKTROFOTOMETRE TASARIMI,

### GERÇEKLEŞTİRİLMESİ, KALİBRASYONU VE AYRINTILI TEST ANALİZİ

### BİTİRME RAPORU

Samet KILIÇ

221903022

NİSAN 2026

MUŞ


### T.C. MUŞ ALPARSLAN ÜNİVERSİTESİ

UYGULAMALI BİLİMLER FAKÜLTESİ

BİLİŞİM SİSTEMLERİ VE TEKNOLOJİLERİ BÖLÜMÜ

### ARDUINO TABANLI DÜŞÜK MALİYETLİ

### SPEKTROFOTOMETRE

### TASARIMI, GERÇEKLEŞTİRİLMESİ, KALİBRASYONU VE

### AYRINTILI TEST ANALİZİ

Samet KILIÇ

221903022

Raporun Bölüme Verildiği Tarih: 29 / 03 / 2026

Tez Danışmanı: Dr. Öğr. Üyesi Ali ÖZDEMİR

Jüri Üyesi: Doç. Dr. Öğr. Üyesi Özer KURT

### ÖNSÖZ

Bu rapor, Muş Alparslan Üniversitesi Uygulamalı Bilimler Fakültesi Bilişim Sistemleri

ve Teknolojileri Bölümü lisans programı kapsamında yürütülen bitirme çalışmasının ayrıntılı raporlaştırılmış halidir. Çalışmanın temel hedefi, düşük maliyetli ve erişilebilir bileşenler kullanılarak eğitim amaçlı kullanılabilecek bir spektrofotometre prototipi geliştirmek, bu prototipin ölçüm mantığını doğrulamak ve proje süresince elde edilen teknik bulguları sistematik biçimde belgelemektir.

Çalışma sürecinde yalnızca bir donanım düzeneği kurulmamış; aynı zamanda optik ölçüm mantığı, sensörün analog ve dijital davranışı, devre bağlantıları, Arduino tabanlı veri toplama, yükleme ve haberleşme sorunlarının giderilmesi, yanlış formüllerin elenmesi ve dark / blank referanslı daha güvenilir bir hesaplama algoritmasına geçilmesi gibi çok sayıda mühendislik problemi ele alınmıştır.

Rapor hazırlanırken amaç, yalnızca çalışır bir düzenek sunmak değil; proje başlangıcından ölçüme hazır son hâle kadar geçen sürecin, karşılaşılan zorlukların, deneysel gözlemlerin, alınan tasarım kararlarının ve geliştirilen çözüm yöntemlerinin akademik bir bütünlük içinde aktarılması olmuştur. Bu nedenle bu metin, klasik kısa proje özeti formatından daha ayrıntılı tutulmuş; sensör modülünün alt birimleri, test aşamaları, hata mesajları, kullanılan formüller ve yorum sınırları ayrı başlıklar altında ayrıntılandırılmıştır.

Çalışma boyunca teknik yönlendirmeleri ve katkıları ile destek sağlayan danışman hocalarım Dr. Öğr. Üyesi Ali ÖZDEMİR’e ve Doç. Dr. Öğr. Üyesi Özer KURT’a teşekkür

ederim. Ayrıca proje denemeleri sırasında destek olan aileme ve arkadaşlarıma da teşekkürü borç bilirim.

### ÖZET

Bu çalışmada, Arduino Uno tabanlı düşük maliyetli bir spektrofotometre prototipinin tasarımı, kurulumu, elektronik bağlantıları, yazılım geliştirme süreci, hata analizi ve ön test sonuçları sunulmaktadır. Proje kapsamında optik sensör modülü, yeşil ışık kaynağı, küvet, 3B baskı / kutu yapısı ve temel elektronik bağlantılar kullanılarak deneysel bir ölçüm düzeneği oluşturulmuştur.

Çalışmanın odak noktası, bir sıvı örneğin ışık geçirgenliğini ve absorbansını ölçebilen basit ama öğretici bir prototip geliştirmek; sensör karakteristiğini deneysel olarak anlamak ve ölçüm güvenilirliğini artıracak kalibrasyon yaklaşımını belirlemektir. Bu amaçla sensör modülünün AO ve DO çıkışları incelenmiş, analog çıkışın nicel ölçümler için daha uygun olduğu görülmüş ve nihai yazılım AO çıkışı üzerinden geliştirilmiştir.

Yapılan testlerde sensörün ışık arttıkça ham analog değeri düşürdüğü, yani ters mantıklı davrandığı tespit edilmiştir. Bu nedenle doğrudan 1023 = %100 geçirgenlik kabulüne dayanan ilk yaklaşım bırakılmış; bunun yerine dark ve blank referanslarına dayalı göreli bir hesaplama modeli benimsenmiştir. Dark ölçümünde yaklaşık 1023, blank ölçümünde ise yaklaşık 194-210 aralığında ham değerler elde edilmiştir. Blank doğrulama testlerinde geçirgenliğin yaklaşık %98,78-%100 ve absorbansın 0’a çok yakın çıkması, sistemin temel ölçüm mantığının uygun olduğunu göstermiştir.

Rapor içerisinde kuramsal arka plan, kullanılan donanım bileşenleri, sensör modülünün ayrıntılı açıklaması, optik ve mekanik düzenek tasarımı, devre bağlantıları, yazılım geliştirme süreci, hata mesajları, test sonuçları ve proje kısıtları detaylı biçimde ele alınmıştır. Çalışma sonunda prototipin vişne suyu gibi gerçek sıvı örneklerle test edilmeye hazır hale geldiği değerlendirilmiştir.

Anahtar Kelimeler: spektrofotometre, Arduino Uno, absorbans, geçirgenlik, optik sensör, dark ve blank kalibrasyonu, düşük maliyetli ölçüm sistemi.

### ABSTRACT

This report presents the design, implementation, calibration approach, troubleshooting process and preliminary test results of a low-cost Arduino Uno based spectrophotometer prototype. The experimental setup was built by combining an optical sensor module, a green light source, a cuvette, a custom enclosure and basic electronic interconnections.

The main objective was to develop a simple but functional platform capable of estimating transmittance and absorbance values, while also documenting how the sensor behaves under different lighting conditions. Both AO and DO outputs of the module were examined; the analog AO output was found to be the only practical option for quantitative measurements.

Experiments showed that the selected sensor behaves inversely: as the received light increases, the raw analog value decreases. Therefore, the initial direct-percentage approach was abandoned and replaced with a relative model based on dark and blank references. A dark reference of approximately 1023 and a blank reference in the range of 194-210 were obtained. In blank verification tests, transmittance remained close to 100% and absorbance stayed near zero, indicating that the basic measurement logic is physically meaningful for a prototype-level system.

The report details the theoretical background, hardware components, optical layout, electrical connections, software development phases, error messages, debugging strategy, test results and limitations of the prototype. At the end of the study, the system was considered ready for further experiments with real liquid samples such as cherry juice.

Keywords: spectrophotometer, Arduino Uno, absorbance, transmittance, optical sensor, dark and blank calibration, low-cost measurement system.

### İÇİNDEKİLER

1. GENEL BİLGİLER (GİRİŞ) | 11
1.1. Spektrofotometrenin Tanımı ve Kullanım Alanları | 12
1.2. Problem Tanımı ve Motivasyon | 13
1.3. Çalışmanın Amacı, Kapsamı ve Sınırları | 14
1.4. Spektrofotometrik Ölçümün Kuramsal Temeli | 15
1.5. Beer-Lambert Yaklaşımı ve Bu Projeye Uyarlanması | 16
1.6. Dark ve Blank Referans Kavramlarının Önemi | 17
2. KULLANILAN DONANIM BİLEŞENLERİ | 19
2.1. Arduino Uno Geliştirme Kartı | 20
2.2. MH-Sensor-Series Flying Fish Sensör Modülü | 22
2.3. Sensör Modülündeki Alt Birimlerin Açıklanması | 24
2.4. AO ve DO Çıkışlarının Teknik Değerlendirmesi | 27
2.5. Işık Kaynağı, Küvet ve 3B Baskı / Kutu Gövde | 29
2.6. Neden Profesyonel Fotodedektör Yerine Bu Modül Tercih Edildi? | 32
3. SİSTEM TASARIMI VE OPTİK YERLEŞİM | 33
3.1. Mekanik Yerleşim ve Ölçüm Geometrisi | 34
3.2. Optik Yol ve Işık Geçişi | 35
3.3. Dış Işık Sızıntısı ve Gövde Tasarımının Etkisi | 36
3.4. Kalibrasyon Mantığı ve Referans Koşulları | 38
4. DEVRE BAĞLANTILARI VE ELEKTRONİK ÇALIŞMA MANTIĞI | 40
4.1. Temel Bağlantı Düzeni | 41
4.2. AO ve DO Çıkışlarının Proje Açısından Değerlendirilmesi | 43
4.3. Besleme, LM393 Karşılaştırıcı ve Trimpotun Rolü | 45
5. YAZILIM GELİŞTİRME SÜRECİ | 46
5.1. İlk Analog Okuma Denemeleri | 47
5.2. Işık Tepkisi Testi ve Sensör Davranışının Analizi | 49
5.3. Hatalı Kod Yaklaşımları ve Nedenleri | 51
5.4. Arduino Yükleme ve Haberleşme Sorununun Giderilmesi | 53
5.5. Dark ve Blank Referanslı Nihai Hesaplama Modeli | 55
5.6. Nihai Kod Yapısı | 57
5.7. Nihai Kodun Satır Bazlı Açıklaması - Bölüm 1 | 59
5.8. Nihai Kodun Satır Bazlı Açıklaması - Bölüm 2 | 60
6. YAPILAN TESTLER VE ELDE EDİLEN SONUÇLAR | 61
6.1. Sensör Tanılama Testi | 55
6.2. Flaş / Işık Tepkisi Testi | 56

### İÇİNDEKİLER (Devam)

6.3. Dark Testi | 65
6.4. Blank Testi | 67
6.5. Blank Doğrulama ve Ölçüm Kararlılığı | 69
6.6. Ölçüm Sonuçlarının Toplu Değerlendirmesi | 71
6.7. Vişne Suyu Testi İçin Beklenen Davranış | 74
7. HATA ANALİZİ VE ÇÖZÜM SÜRECİ | 76
7.1. Sensör Tipi Belirsizliği ve Doğru Yorumlama | 77
7.2. Analog ve Dijital Çıkışın Karıştırılması | 79
7.3. Yükleme Hatası ve Geliştirme Ortamı Problemleri | 80
7.4. Hatalı Formül Kullanımının Sonuçları | 81
7.5. Fiziksel Hizalama, Işık Sızıntısı ve Operatör Etkisi | 82
7.6. Çoklu Örnekleme ve Ortalama Alma Yaklaşımı | 84
8. DEĞERLENDİRME, KISITLAR VE GELECEK ÇALIŞMALAR | 85
8.1. Projenin Başarı Düzeyi | 86
8.2. Mevcut Kısıtlar | 87
8.3. Gelecek Çalışmalar | 89
9. SONUÇ | 90
KAYNAKÇA | 91
EKLER | 92
Ek-1. Nihai Arduino Kodu - Bölüm 1 | 93
Ek-1. Nihai Arduino Kodu - Bölüm 2 | 94
Ek-2. İlk analog okuma kodu | 95
Ek-3. İlk LDR-benzeri yaklaşım (hatalı yorum örneği) | 96
Ek-4. Dijital pin üzerinden ölçüm denemesi | 97
Ek-5. Proje görselleri seçkisi - 1 | 98
Ek-5. Proje görselleri seçkisi - 2 | 54
Ek-5. Proje görselleri seçkisi - 3 | 55
Ek-5. Proje görselleri seçkisi - 4 | 56

### ŞEKİLLER DİZİNİ

Şekil 1. Sensör modülünün ön ve arka yüzünü gösteren yakın çekim kolajı | 23
Şekil 2. Prototip spektrofotometre düzeneğinin genel görünümü | 30
Şekil 3. Işık kaynağının aktif olduğu optik düzenek görüntüsü | 31
Şekil 4. Arduino Uno ile sensör modülü arasındaki devre bağlantı şeması | 42
Şekil 5. İlk analog okuma denemesine ait Arduino IDE ekran görüntüsü | 48
Şekil 6. Flaş / ışık tepkisi testine ait seri monitör ekran görüntüsü | 50
Şekil 7. Nihai Arduino ölçüm ve hesaplama kodu ekran görüntüsü | 58
Şekil 8. Karanlık / ışıksız durumda alınan dark ölçümü ekran görüntüsü | 66
Şekil 9. Blank ölçümüne ait seri monitör ekran görüntüsü | 68
Şekil 10. Sensör modülüne ait ek saha görselleri | 78
Ek Şekil 1. Prototip düzeneğin genel görünümü | 99
Ek Şekil 2. Işık kaynağının aktif olduğu deney görüntüsü | 54
Ek Şekil 3. Çıktı Görseli | 55
Ek Şekil 4. Çalışma sürecinde alınan ekran görüntüleri kolajı | 56

### TABLOLAR DİZİNİ

Tablo 1. Spektrofotometrenin temel ölçüm büyüklükleri | 18
Tablo 2. Arduino Uno kartının proje açısından öne çıkan teknik özellikleri | 21
Tablo 3. Sensör modülü pin açıklamaları | 25
Tablo 4. Sensör modülünde bulunan alt birimler ve işlevleri | 26
Tablo 5. AO ve DO çıkışlarının proje açısından karşılaştırılması | 28
Tablo 6. Optik yerleşimde sonuçları etkileyen temel risk faktörleri | 37
Tablo 7. Dark, blank ve örnek ölçümlerinin anlamı | 39
Tablo 8. Kart üzerindeki hatların bağlantı haritası | 44
Tablo 9. Proje sürecinde denenen kod yaklaşımları ve sınırlılıkları | 52
Tablo 10. Karşılaşılan hata mesajları ve çözüm adımları | 54
Tablo 11. Nihai algoritmada kullanılan değişkenler ve fiziksel karşılıkları | 56
Tablo 12. Testlerin uygulanma sırası ve amacı | 63
Tablo 13. Blank testinde gözlenen ham değerler ve hesaplanan sonuçlar | 70
Tablo 14. Yapılan testler ve gözlemler | 72
Tablo 15. Dark ve blank ölçümlerinin özet sonuçları | 73
Tablo 16. Vişne suyu testi için beklenen yorum aralıkları | 54
Tablo 17. Sık karşılaşılan sorunlar için hızlı kontrol listesi | 55
Tablo 18. Prototip düzeyindeki güçlü yönler, sınırlılıklar ve iyileştirme önerileri | 56

### KISALTMALAR VE SEMBOLLER

Kısaltma / Sembol | Açıklama
AO | Analog Output (Analog Çıkış)
DO | Digital Output (Dijital Çıkış)
ADC | Analog-Dijital Çevirici
LM393 | Karşılaştırıcı entegre
T | Geçirgenlik (Transmittance)
A | Absorbans (Absorbance)
darkRaw | Karanlık referans ölçümü
blankRaw | Boş küvet referans ölçümü
rawValue | Sensörden anlık okunan ham analog değer
sampleCount | Ortalama için alınan örnek sayısı

Tablo 0. Rapor içerisinde kullanılan temel kısaltmalar ve semboller.

### 1. GENEL BİLGİLER (GİRİŞ)

Bu bitirme çalışmasında, düşük maliyetli bileşenlerle çalışabilen ve temel spektrofotometrik ölçüm mantığını gösterebilen bir prototip cihaz geliştirilmiştir. Çalışma, profesyonel laboratuvar cihazı üretmekten çok, optik ölçümün mantığını görünür kılan, yazılım ile donanım kararlarını belgeleyen ve eğitim amaçlı kullanılabilecek bir çekirdek yapı ortaya koymayı amaçlamaktadır.

Raporun bu bölümü, proje motivasyonunu, kullanılan kavramları ve ölçüm yaklaşımının neden klasik laboratuvar düzeneklerinden daha sade fakat yine de öğretici sayılabileceğini açıklamaktadır. İzleyen bölümlerde ise bileşen seçimi, sensör karakteristiği, devre bağlantısı,

yazılım, testler ve hata analizi ayrıntılı biçimde sunulmaktadır.

### 1.1. Spektrofotometrenin Tanımı ve Kullanım Alanları

Spektrofotometre, belirli bir dalga boyundaki ışığın bir örnek tarafından ne kadar geçirildiğini veya ne kadar soğurulduğunu nicel olarak değerlendirmek için kullanılan ölçüm cihazıdır. Bir örnekten geçen ışık miktarı ile referans durum arasındaki fark ölçülerek kimyasal veya fiziksel yorum yapılabilir. Özellikle sıvı örneklerin optik karakterizasyonunda

bu cihazların yeri büyüktür.

Kimya laboratuvarlarında derişim tayini, gıda analizlerinde renk ve kalite değerlendirmesi, çevre ölçümlerinde çözeltideki maddelerin takibi ve biyolojik örneklerin incelenmesi gibi çok farklı kullanım alanları vardır. Eğitim ortamlarında ise bu cihazlar; ışık, madde ve ölçüm arasındaki ilişkiyi somutlaştırdığı için öğretici deneyler açısından önem taşır.

Profesyonel cihazlarda monokromatör, yüksek kararlı ışık kaynağı, hassas fotodedektör ve iyi yalıtılmış örnek odası bulunur. Bu projede ise benzer mantığın düşük maliyetli bir yansıması hedeflenmiş; temel prensipler korunurken sistem olabildiğince erişilebilir tutulmuştur.

### 1.2. Problem Tanımı ve Motivasyon

Ticari spektrofotometrelerin önemli bir bölümü öğrenci projeleri ve küçük ölçekli eğitim laboratuvarları için yüksek maliyetli olabilmektedir. Buna karşılık, spektrofotometrik ölçümün temelini oluşturan ışık kaynağı, örnek, optik yol ve algılama birimi kavramları daha basit donanımlarla da deneysel olarak gösterilebilir. Bu bitirme çalışmasının çıkış noktası, tam da bu boşluğu doldurmaktır.

Projenin motivasyonu, bir cihazı yalnızca satın alıp kullanmak yerine onun temel çalışma mantığını bileşen seviyesinde anlamaktır. Bu yaklaşım sayesinde, hem optik ölçüm kuramı somut olarak gözlenmekte hem de Arduino programlama, analog veri okuma, sensör davranışını yorumlama, hata ayıklama ve kalibrasyon gibi çok sayıda teknik beceri tek bir sistem içinde bütünleşmektedir.

Dolayısıyla proje, yalnızca bir donanım düzeni kurma denemesi değil; gömülü sistemler, deneysel fizik, elektronik ve veri yorumlama basamaklarının birlikte işletildiği bir mühendislik uygulamasıdır.

### 1.3. Çalışmanın Amacı, Kapsamı ve Sınırları

Çalışmanın temel amacı, Arduino Uno merkezli düşük maliyetli bir spektrofotometre prototipi geliştirerek ışık geçirgenliği ve absorbansın hesaplanabileceği bir ölçüm altyapısı oluşturmaktır. Bu amaç doğrultusunda sensör modülü tanımlanmış, optik yerleşim hazırlanmış, devre bağlantıları kurulmuş, yazılım geliştirilmiş ve dark / blank referansları belirlenmiştir.

Çalışma kapsamı; sensörün AO ve DO çıkış davranışlarının incelenmesi, yükleme ve haberleşme sorunlarının giderilmesi, hatalı formül yaklaşımlarının elenmesi, nihai ölçüm algoritmasının tasarlanması ve dark ile blank testlerinin yapılmasıdır. Vize dönemi boyunca gerçek sıvı örnekler üzerinde tam deneysel seri henüz gerçekleştirilmemiş; ancak sistemin bu aşamaya hazır hale getirilmesi hedeflenmiştir.

Bu raporda, gerçekten yapılmış testler sonuç olarak sunulmuş; vişne suyu deneyi ise planlanan uygulama olarak değerlendirilmiştir. Böylece rapor, eldeki verileri abartmadan ve uydurma sonuç üretmeden dürüst bir belgelendirme yaklaşımı benimsemektedir.

### 1.4. Spektrofotometrik Ölçümün Kuramsal Temeli

Spektrofotometrik ölçümde iki temel büyüklük öne çıkar: geçirgenlik ve absorbans. Geçirgenlik, örnekten geçen ışığın referans durumda geçen ışığa oranıdır. Bir örnek ne kadar şeffaf ise geçirgenlik değeri o kadar yüksek olur. Koyu veya ışığı daha fazla soğuran örneklerde ise sensöre ulaşan ışık miktarı azalır.

Absorbans ise örneğin ışığı ne ölçüde soğurduğunu temsil eder ve geçirgenlik ile logaritmik bir ilişki içindedir. Boş küvet veya referans durumda absorbansın sıfıra yaklaşması beklenir. Böylece sistemin referans koşulu ile örnek koşulu arasındaki fark nicel olarak yorumlanabilir.

Bu projede kullanılan sensör modülü, üzerine düşen ışık miktarı arttığında daha düşük ham analog değer ürettiğinden, klasik ham değer yorumu doğrudan uygulanamamıştır. Dolayısıyla teorik büyüklüklerin prototipe uygun yorumlanması için dark ve blank referansları üzerinden göreli bir model kurulmuştur.

### 1.5. Beer-Lambert Yaklaşımı ve Bu Projeye Uyarlanması

Klasik spektrofotometri literatüründe absorbans, A = -log10(T) ifadesi ile tanımlanır. Bu yaklaşım, ideal optik koşullarda Beer-Lambert yasasının daha genel yorumuna bağlanır. Ancak düşük maliyetli prototiplerde mutlak yoğunluk ölçmek yerine göreli davranışı doğru kurmak çoğu zaman daha kritik hale gelir.

Bu projede amaç, laboratuvar kalibrasyonu yapılmış hassas bir cihaz üretmekten ziyade, referans ile örnek arasındaki farkı fiziğe uygun bir şekilde okumaktır. Bu nedenle Beer-Lambert yaklaşımının sadeleştirilmiş fakat fiziksel mantığı koruyan bir yorumu kullanılmıştır. Geçirgenlik ve absorbans yine standart biçimde hesaplanmış; ancak ham sensör değerleri önce dark ve blank referansları ile dönüştürülmüştür.

Böylece nihai yazılım, sensörün ters karakteristiğine rağmen fiziksel anlamı olan bir yorum üretmiştir. Blank durumunda absorbansın sıfıra çok yakın çıkması, bu uyarlamanın pratik açıdan doğru yönde olduğunu göstermiştir.

### 1.6. Dark ve Blank Referans Kavramlarının Önemi

Dark referansı, ışık kaynağı kapalı iken veya sensör tam karanlıkta iken alınan ölçümdür. Bu referans, sistemin alt sınırını ve sensörün karanlık koşulundaki davranışını tanımlar. Projedeki ölçümlerde dark değerin yaklaşık 1023 olması, sensörün karanlıkta maksimum ham sayım seviyesine yaklaştığını göstermiştir.

Blank referansı ise ışık kaynağı açık ve küvet boş halde iken alınan ölçümdür. Bu koşul, sistemdeki maksimum referans ışık geçiş durumunu temsil eder. Ölçümlerde blank değerin

yaklaşık 194-210 aralığında olması, sistemin aydınlık referans koşulunu tanımlamak için yeterli bir aralık sunmuştur.

Dark ve blank değerlerinin birlikte kullanılması, sensörün ters mantığına rağmen göreli ışık miktarını kurmanın anahtarı olmuştur. Bu nedenle projede doğrudan ham değer yerine, darkRaw - rawValue ve darkRaw - blankRaw ilişkileri kullanılmıştır.

Kavram | Açıklama | İfade
Dark | Işık kapalı iken veya sensör tam karanlıkta iken alınan referans ölçüm | darkRaw
Blank | Işık açık ve boş küvet varken alınan referans ölçüm | blankRaw
Örnek | Ölçülmek istenen sıvı varken alınan ham ölçüm değeri | sample / rawValue
Geçirgenlik | Örnekten geçen ışığın blank ölçümüne oranı | T = I_sample / I_blank
Absorbans | Geçirgenliğe bağlı hesaplanan soğurma büyüklüğü | A = -log10(T)

Tablo 1. Spektrofotometrenin temel ölçüm büyüklükleri.

### 2. KULLANILAN DONANIM BİLEŞENLERİ

Bu bölümde, prototipin oluşturulmasında kullanılan tüm temel bileşenler yalnızca isimleriyle değil, proje açısından neden seçildikleri ve hangi görevi üstlendikleri ile birlikte açıklanmaktadır. Donanım bileşenlerinin dikkatli incelenmesi, düşük maliyetli bir sistemin hangi sınırlara ve hangi avantajlara sahip olduğunu anlamak açısından önemlidir.

Seçim yapılırken erişilebilirlik, maliyet, elde bulunan malzemelerle uyumluluk, Arduino ile kolay bağlantı kurulabilmesi ve eğitim amaçlı gözlemlenebilir sonuç üretmesi gibi ölçütler dikkate alınmıştır.

### 2.1. Arduino Uno Geliştirme Kartı

Arduino Uno, prototipte veri toplama ve hesaplama işlevlerinden sorumlu merkez kontrol kartı olarak kullanılmıştır. ATmega328P mikrodenetleyicisi temelinde çalışan bu kart, analog girişlerden veri okuyabilmesi, kolay programlanabilir olması ve yaygın topluluk desteği nedeniyle tercih edilmiştir.

Kart üzerindeki A0 analog girişi sensör modülünün AO pininden gelen sinyalin okunmasında kullanılmış; 5V ve GND pinleri ise sensör modülüne besleme sağlamak için kullanılmıştır. Geliştirme süreci boyunca seri monitör yardımıyla ölçümlerin anlık izlenebilmesi, kartın bu tür deneysel projelerde önemli bir avantaj sunduğunu göstermiştir.

Arduino Uno üzerindeki 10 bit ADC çözünürlüğü bu projede yeterli görülmüştür. Bununla birlikte, ilerleyen aşamalarda daha yüksek hassasiyet istenirse harici ADC kullanımı veya daha yüksek çözünürlüklü platformlara geçiş düşünülebilir.

Özellik | Değer / Açıklama | Projeye Etkisi
Mikrodenetleyici | ATmega328P | Basit ve güvenilir geliştirme ortamı sağlar
Analog giriş sayısı | 6 adet | AO hattının doğrudan okunmasına olanak tanır
ADC çözünürlüğü | 10 bit (0-1023) | Ham ışık verisinin nicel olarak izlenmesini sağlar
Besleme gerilimi | 5V | Sensör modülü ile doğrudan uyumludur
Programlama ortamı | Arduino IDE | Kod yükleme ve seri monitör takibi kolaydır
Topluluk desteği | Çok yaygın | Sorun çözme ve örnek geliştirme süreçlerini hızlandırır

Tablo 2. Arduino Uno kartının proje açısından öne çıkan teknik özellikleri.

### 2.2. MH-Sensor-Series Flying Fish Sensör Modülü

Projede algılayıcı olarak MH-Sensor-Series Flying Fish ibaresine sahip bir sensör modülü kullanılmıştır. Modül üzerinde VCC, GND, DO ve AO pinleri; bir trimpot, iki gösterge LED’i ve karşılaştırıcı devre bulunmaktadır. Bu yapı, modülün hem eşik tabanlı dijital davranış gösterebildiğini hem de sürekli değişen analog sinyal üretebildiğini göstermektedir.

Modül web ortamında çoğu zaman alev sensörü veya IR algılama modülü olarak sınıflandırılsa da, proje sürecinde pratik olarak optik algılayıcı gibi kullanılmıştır. Yani AO çıkışı, üzerine ulaşan ışık miktarına göre değişen bir analog sinyal üretmiş ve bu sinyal spektrofotometrik ölçüm mantığı içinde değerlendirilmiştir.

Yapılan denemelerde telefon flaşı sensöre yaklaştırıldığında analog değerin düştüğü gözlenmiş, bu durum modülün ışık arttıkça daha düşük ham değer üretmesi nedeniyle özel bir yorum gerektirdiğini ortaya koymuştur.


Şekil 1. Sensör modülünün ön ve arka yüzünü gösteren yakın çekim kolajı.

### 2.3. Sensör Modülündeki Alt Birimlerin Açıklanması

Modülün uç kısmındaki algılayıcı eleman ilk bakışta klasik bir LED gibi görünse de, proje testlerinde ışık algılayan bir eleman gibi davranmıştır. Bu durum özellikle modülün ön ve arka yüzünün incelenmesi ve AO hattından alınan verilerin ışık şiddetine bağlı değişmesinden anlaşılmıştır.

Mavi trimpot, modül üzerindeki LM393 karşılaştırıcı devresinin eşik seviyesini ayarlamak için kullanılır. Bu parça, özellikle DO çıkışının hangi seviyede 0 veya 1 geçişi yapacağını belirler. Nicel absorbans ölçümlerinde ise asıl yararlı kanal AO hattı olduğundan trimpot proje boyunca ikincil öneme sahip olmuştur.

Gösterge LED’leri, modülün enerji alıp almadığının ve eşik davranışının hızlı şekilde anlaşılmasını sağlamıştır. Böylece ilk kurulum sırasında besleme hataları veya gevşek bağlantılar daha kolay fark edilmiştir.

Pin / Birim | Görevi | Projede Kullanımı
VCC | Sensör beslemesi | Arduino 5V pinine bağlandı
GND | Toprak hattı | Arduino GND pinine bağlandı
AO | Analog çıkış | Absorbans hesabında kullanıldı
DO | Dijital çıkış | Yalnızca eşik davranışını incelemek için test edildi
Trimpot | Eşik ayarı | DO davranışını etkiler; analog ölçümde ikincil rol oynar
Gösterge LED’leri | Besleme ve durum göstergesi | Kurulum doğrulamasında yardımcı oldu

Tablo 3. Sensör modülü pin açıklamaları.

Alt Birim | Teknik Rol | Projeye Etkisi
Algılayıcı uç | Işık seviyesine tepki veren asıl eleman | AO hattındaki değişimin kaynağıdır
LM393 karşılaştırıcı | Analog seviyeyi eşik tabanlı dijital sinyale dönüştürür | DO çıkışını üretir
Trimpot | Eşik seviyesini ayarlar | DO geçişini belirler
Durum LED’i | Modülün enerjili olduğunu gösterir | Kurulum kontrolünü kolaylaştırır
Çıkış pinleri | AO ve DO verilerini iletir | Analog ve dijital karşılaştırma yapılmasını sağlar

Tablo 4. Sensör modülünde bulunan alt birimler ve işlevleri.

### 2.4. AO ve DO Çıkışlarının Teknik Değerlendirmesi

AO çıkışı, ışık şiddetindeki değişimlere karşılık sürekli değişen analog değer ürettiği için absorbans hesabına uygundur. Bu hat üzerinden 0 ile 1023 arasında değişen veriler okunabilmiş ve sensörün ışığa verdiği tepki nicel olarak gözlenebilmiştir.

DO çıkışı ise LM393 karşılaştırıcı devresinin belirlediği eşik seviyesine göre yalnızca 0 veya 1 bilgisi verir. Bu bilgi alarm, tetikleme veya temel durum tespiti için yararlı olabilir; ancak nicel optik ölçüm için yeterli değildir. İlk denemelerde DO üzerinden geçirgenlik

türetmeye çalışmak, verinin iki seviyeye sıkışması nedeniyle sağlıklı sonuç vermemiştir.

Sonuç olarak nihai sistemde AO hattı zorunlu ölçüm kanalı olarak kabul edilmiş, DO hattı ise sensör modülünün davranışını anlamaya yardımcı olan açıklayıcı bir unsur olarak değerlendirilmiştir.

Özellik | AO | DO
Veri tipi | Sürekli analog değer | 0 / 1 dijital durum
Ölçüm hassasiyeti | Nicel yorum için uygundur | Yalnızca eşik bilgisi verir
Absorbans hesabı | Kullanılabilir | Yetersiz
Trimpot etkisi | Dolaylı / sınırlı | Belirgin
Projede rolü | Nihai ölçüm kanalı | Karşılaştırma ve test amaçlı

Tablo 5. AO ve DO çıkışlarının proje açısından karşılaştırılması.

### 2.5. Işık Kaynağı, Küvet ve 3B Baskı / Kutu Gövde

Prototipte ışık kaynağı olarak yeşil renkli bir ışık kaynağı kullanılmıştır. Bu kaynak, küvet içerisindeki sıvı örneğe belirli bir doğrultuda ışık göndermekte; sensör modülü ise karşı tarafta bu ışığın ne kadarını algıladığını ölçmektedir. Renkli sıvılar üzerinde absorbans değişimi gözlenebilmesi için yeşil ışık pratik ve görsel olarak anlamlı bir seçim olmuştur.

Küvet, örneğin sabit bir geometride tutulmasını sağlayan temel elemandır. Ölçümün

tekrar edilebilir olması için küvetin her denemede aynı yöne ve aynı konuma yerleştirilmesi gerekir. Bu nedenle küvet yuvası ve tutucu yapı, sistem kararlılığı açısından kritik rol oynamıştır.

3B baskı / kutu gövde, ışık kaynağı ile sensörün aynı optik eksende kalmasına yardımcı olmakta ve dış ortam ışığının sisteme sızmasını azaltmaktadır. Özellikle dark ve blank

testlerinde daha tutarlı sonuçlar alınmasında gövde tasarımının önemli katkısı olmuştur.


Şekil 2. Prototip spektrofotometre düzeneğinin genel görünümü.

Şekil 3. Işık kaynağının aktif olduğu optik düzenek görüntüsü.

### 2.6. Neden Profesyonel Fotodedektör Yerine Bu Modül Tercih Edildi?

Bitirme projesinin temel hedeflerinden biri düşük maliyetli ve erişilebilir bir prototip geliştirmek olduğundan, piyasada kolay bulunan ve hazır pin yapısına sahip bir modül ile çalışmak tercih edilmiştir. Fotodiyot + transimpedans yükselteç temelli profesyonel bir algılama katı daha hassas sonuçlar verebilirdi; ancak bu aşamada öncelik çalışan, öğretici ve geliştirilebilir bir düzenek ortaya koymaktı.

Hazır modül kullanımı, lehimleme ve analog ön yükselteç tasarımını ikinci plana iterek dikkati yazılım algoritmasına, optik yerleşime ve kalibrasyon mantığına odaklamıştır. Bu tercih aynı zamanda öğrencilik düzeyinde prototip geliştirme, hata ayıklama ve ölçüm mantığını gözlemleme süreçlerini de kolaylaştırmıştır.

Dolayısıyla modül seçimi, yalnızca maliyet düşürme kararı değil; eğitsel hedeflerle uyumlu bir basitleştirme stratejisi olarak değerlendirilmelidir.

### 3. SİSTEM TASARIMI VE OPTİK YERLEŞİM

Bu bölüm, prototip içinde ışık kaynağı, küvet ve sensörün nasıl konumlandırıldığını; optik yolun nasıl tanımlandığını ve ölçüm kararlılığını etkileyen fiziksel faktörlerin nasıl değerlendirildiğini açıklamaktadır. Prototip düzeneğin başarısı, yalnızca doğru koddan değil, aynı zamanda tekrar edilebilir fiziksel geometri kurabilmekten de geçmektedir.

Özellikle düşük maliyetli sistemlerde mekanik yerleşimin küçük farklılıklar üretmesi

çok olağandır. Bu nedenle optik yerleşim ve dış ışık kontrolü, yazılım kadar kritik kabul edilmiştir.

### 3.1. Mekanik Yerleşim ve Ölçüm Geometrisi

Sistem tasarlanırken ışık kaynağı, küvet ve sensörün aynı eksen üzerinde konumlandırılmasına dikkat edilmiştir. Bu düzen sayesinde ışık kaynağından çıkan ışın doğrudan örneğe yönelmiş, örnekten geçen ışık ise sensör modülüne ulaşmıştır.

Optik ölçümlerde mekanik tekrar edilebilirlik kritik öneme sahiptir. Küvetin her denemede farklı konumda durması veya sensörün açı yapması, sensöre ulaşan ışık miktarını değiştirerek sonuçların tutarsız olmasına neden olabilir. Bu nedenle kutu içinde sabit yuva kullanılması sadece montaj kolaylığı değil, ölçüm tekrarlanabilirliği açısından da önemlidir.

Prototipte küvet yuvası ve sensörün konumu her denemede aynı geometrinin korunmasına yardımcı olacak şekilde ayarlanmıştır. Bu karar, blank ölçümlerinin 194-210 aralığında sınırlı dalgalanma ile kalmasına katkı sunmuştur.

### 3.2. Optik Yol ve Işık Geçişi

Prototipte ışık kaynağı ile sensör arasında tek doğrultulu bir optik yol oluşturulmuştur. Ölçüm sırasında küvet bu yol üzerine yerleştirilmekte ve ışığın örnek içinden geçerek sensöre ulaşması beklenmektedir. İdeal durumda blank ölçümünde sensöre maksimum ışık, daha koyu

örneklerde ise daha az ışık ulaşır.

Gerçek prototipte optik yol tam anlamıyla kolimasyonlu değildir; yani ışık profesyonel sistemlerde olduğu gibi çok dar ve ideal bir demet halinde ilerlememektedir. Buna rağmen kapalı kutu yapısı ve kısa mesafe kullanımı sayesinde yeterli bir deneysel düzenek elde edilmiştir.

Bu aşamada sistem, mutlak laboratuvar doğruluğundan çok blank ve örnek arasındaki göreli farkı kararlı biçimde göstermeye odaklanmıştır. Dolayısıyla amaç, referans ile örnek arasındaki trendi güvenilir şekilde okuyabilen bir çekirdek mimari kurmaktır.

### 3.3. Dış Işık Sızıntısı ve Gövde Tasarımının Etkisi

Dış ortam ışığı, prototip tipindeki optik ölçüm düzeneklerinde en sık karşılaşılan hata kaynaklarından biridir. Eğer kutu yapısı yeterince kapalı değilse sensör yalnızca örnekten geçen ışığı değil, çevreden gelen rastgele ışığı da görür ve sonuçlar sapabilir.

Bu projede kullanılan kutu / 3B baskı gövde, dış ışık sızıntısını azaltmak ve ölçümler arasında sabit bir optik hacim oluşturmak için kritik rol oynamıştır. Özellikle dark ölçümünün

yaklaşık 1023’e ulaşabilmesi, sensörün karanlık referansının büyük ölçüde korunabildiğini göstermektedir.

Bununla birlikte prototipin laboratuvar tipi bir optik hücre kadar yalıtılmış olmadığı da kabul edilmelidir. Bu nedenle ölçüm yapılırken çevre ışığının sabit tutulması, operatör gölgesi ve el hareketlerinin optik hatta girmemesi önemlidir.

Risk Faktörü | Muhtemel Etki | Önerilen Önlem
Küvetin eğik yerleştirilmesi | Geçen ışık miktarını değiştirir | Her ölçümde aynı yön ve yuvayı kullanmak
Dış ışık sızıntısı | Blank ve sample değerlerini bozar | Kapalı gövde ve sabit ortam ışığı kullanmak
Sensör açısının kayması | Algılama miktarını etkiler | Sensörü sabit konuma sabitlemek
Işık kaynağının oynaklığı | Ham değerde dalgalanma üretir | Sabit besleme ve çoklu örnekleme yapmak
Operatör müdahalesi | Kısa süreli gölgelenme oluşturur | Ölçüm sırasında düzeneğe dokunmamak

Tablo 6. Optik yerleşimde sonuçları etkileyen temel risk faktörleri.

### 3.4. Kalibrasyon Mantığı ve Referans Koşulları

Kalibrasyon, bu projede profesyonel cihazlardaki kapsamlı çok noktalı kalibrasyondan ziyade referans koşullarının doğru belirlenmesi şeklinde ele alınmıştır. Amaç, sensörün kendi karakteristiği içinde anlamlı bir dark ve blank çifti bularak ölçümleri bu çifte göre yorumlamaktır.

Dark referansı, ışık kapalı ve sistem karanlık iken alınan ölçümdür. Blank referansı ise ışık açık ve küvet boş iken alınır. Bu iki sınır, sensörden okunan ham değerin fiziksel bağlama oturtulmasını sağlar. Kullanılan modül ters mantıklı davrandığı için, ham değeri doğrudan ışık şiddeti sanmak yerine referanslar üzerinden yeniden tanımlamak gerekmiştir.

Bu raporda kullanılan nihai yaklaşım, I_blank = darkRaw - blankRaw ve I_sample = darkRaw - rawValue bağıntılarına dayanmaktadır. Elde edilen T ve A değerleri de bu ara büyüklüklerden türetilmiştir.

Durum | Koşul | Fiziksel Anlam | Projede Kullanımı
Dark | Işık kapalı / tam karanlık | Sensörün karanlık sınırı | darkRaw = 1023 referansı
Blank | Işık açık + boş küvet | Referans ışık geçiş durumu | blankRaw = yaklaşık 200
Sample | Işık açık + örnek | Örneğe ait gerçek ölçüm durumu | Transmittance ve absorbans hesabı

Tablo 7. Dark, blank ve örnek ölçümlerinin anlamı.

### 4. DEVRE BAĞLANTILARI VE ELEKTRONİK ÇALIŞMA MANTIĞI

Bu bölümde sensör modülü ile Arduino Uno arasındaki bağlantı düzeni, AO ve DO çıkışlarının nasıl ayrıştırıldığı ve sensör modülündeki karşılaştırıcı yapının proje kararlarını nasıl etkilediği açıklanmaktadır. Elektronik bağlantıların sade ve güvenilir olması, yazılım yorumunun doğru ilerleyebilmesi için ön koşuldur.

Projede karmaşık bir arayüz kartı kullanılmamış; sensör doğrudan Arduino’nun analog girişine bağlanmıştır. Böylece hata ayıklama daha kolay olmuş, her bağlantı tek tek izlenebilmiştir.

### 4.1. Temel Bağlantı Düzeni

Proje sırasında sensörün analog çıkışı kullanılmıştır. Temel bağlantı düzeni AO -> Arduino A0, VCC -> Arduino 5V ve GND -> Arduino GND şeklindedir. Bu bağlantı ile sensör modülünden gelen analog veriler doğrudan Arduino üzerinde okunabilmiştir.

DO pini bazı denemelerde ek olarak incelenmiş olsa da, dijital çıkış yalnızca eşik aşıldı / aşılmadı bilgisini verdiği için absorbans hesabında kullanılmamıştır. Bu sonuç, analog ölçüm gerektiren optik uygulamalarda AO çıkışının zorunlu olduğunu göstermiştir.

Kablo sayısının az tutulması ve bağlantıların sadeleştirilmesi, özellikle yükleme ve haberleşme problemleri yaşandığında sorunun kaynağını izlemeyi kolaylaştırmıştır.


Şekil 4. Arduino Uno ile sensör modülü arasındaki devre bağlantı şeması.

### 4.2. AO ve DO Çıkışlarının Proje Açısından Değerlendirilmesi

AO çıkışı, ışık şiddetindeki değişimlere karşılık sürekli değişen analog değer ürettiği için absorbans hesabına uygundur. Bu hat üzerinden 0 ile 1023 arasında değişen veriler okunabilmiş ve blank ile dark arasındaki fark nicel olarak izlenebilmiştir.

DO çıkışı ise LM393 karşılaştırıcı devresinin belirlediği eşik seviyesine göre yalnızca 0 veya 1 bilgisi verir. Bu özellik, var-yok tipindeki algılama problemleri için anlamlı olsa da, ışık miktarındaki küçük değişimleri temsil edemediğinden bu projedeki amaçla uyumlu değildir.

İlk denemelerde DO pinini kullanarak analog benzeri yorum yapma düşüncesi ortaya

çıkmış, ancak bunun nicel ölçüm için yetersiz olduğu hızla anlaşılmış ve proje AO hattına taşınmıştır.

Hat | Arduino Bağlantısı | Açıklama
AO | A0 | Ham analog veri bu pin üzerinden okundu
VCC | 5V | Sensör modülünün besleme hattı
GND | GND | Ortak toprak bağlantısı
DO | (İsteğe bağlı dijital pin) | Yalnızca eşik davranışını gözlemek için kullanıldı

Tablo 8. Kart üzerindeki hatların bağlantı haritası.

### 4.3. Besleme, LM393 Karşılaştırıcı ve Trimpotun Rolü

Modül 5V ile beslendiğinde üzerindeki durum LED’leri, enerjinin ulaştığını ve bağlantıların temel düzeyde doğru kurulduğunu göstermiştir. Bu görsel geri bildirim, prototip tipinde önemli bir avantajdır; çünkü henüz seri monitör tarafına geçmeden besleme sorunu olup olmadığı anlaşılabilir.

LM393 karşılaştırıcı, modülün dijital davranışını yöneten elemandır. Trimpot çevrildikçe karşılaştırıcının eşik seviyesi değişir ve DO çıkışı buna göre tetiklenir. Ancak AO hattı bu eşiğe doğrudan bağlı nicel bilgi taşıdığı için, absorbans hesabında esas kanal olmayı sürdürmüştür.

Bu bölümden çıkarılan mühendislik sonucu şudur: Modülün üzerinde analog ve dijital katmanların aynı anda bulunması, onu çok amaçlı hale getirmektedir; fakat spektrofotometre benzeri nicel ölçüm işlerinde yalnızca analog katman gerçekten işe yaramaktadır.

### 5. YAZILIM GELİŞTİRME SÜRECİ

Yazılım geliştirme süreci, sensör modülünün davranışını anlamak amacıyla en basit analog okuma kodu ile başlamış, daha sonra hatalı yorumların ayıklanması, yükleme problemlerinin çözülmesi ve nihai dark / blank referanslı algoritmanın oluşturulması ile devam etmiştir. Bu bölümde yalnızca son kod değil, o koda gelene kadar hangi adımların neden değiştirildiği de ayrıntılı biçimde açıklanmaktadır.

Bu yaklaşım önemlidir; çünkü prototip projelerde asıl öğrenme değeri çoğu zaman hatalı denemelerin görülmesi ve neden başarısız olduklarının anlaşılmasında ortaya çıkar.

### 5.1. İlk Analog Okuma Denemeleri

Yazılım geliştirme süreci, sensör modülünün AO hattından gelen ham değerin doğrudan analogRead() komutu ile okunmasıyla başlamıştır. İlk amaç, sensörün gerçekten veri üretip

üretmediğini ve bu verinin seri monitörde izlenebilir olup olmadığını doğrulamaktı.

Bu aşamada hazırlanan en basit Arduino kodu, A0 pininden okunan değeri seri monitöre yazdırmaktaydı. Seri monitörde 1017, 1018 ve 1019 gibi yüksek değerlerin görülmesi, sensörün veri ürettiğini ancak optik koşulların ve yorum mantığının henüz netleşmediğini göstermiştir.

İlk analog denemeler, proje için temel elektriksel doğrulama basamağı işlevi görmüştür.

Veri akışı yoksa daha ileri formüllere geçmenin anlamı olmayacağı için bu basit test kritik önemdedir.


Şekil 5. İlk analog okuma denemesine ait Arduino IDE ekran görüntüsü.

### 5.2. Işık Tepkisi Testi ve Sensör Davranışının Analizi

Daha sonra telefon flaşı sensöre yaklaştırıldığında ham değerin düştüğü gözlenmiş ve sensör davranışının ters mantıklı olduğu anlaşılmıştır. Bu gözlem, yazılım tarafında yapılacak tüm formül düzenlemelerinin temelini oluşturmuştur.

Klasik bir beklentiye göre ışık arttıkça sensör verisinin de artacağı düşünülse de, bu modülde tam tersi bir yapı ortaya çıkmıştır. Dolayısıyla ham analog değeri doğrudan “daha fazla ışık” anlamına gelecek şekilde yorumlamak ciddi fiziksel hata yaratmıştır.

Sensör davranışının bu erken aşamada anlaşılması, projenin geri kalanında yanlış modele ısrar edilmesini engellemiş ve dark / blank yaklaşımına giden yolu açmıştır.


Şekil 6. Flaş / ışık tepkisi testine ait seri monitör ekran görüntüsü.

### 5.3. Hatalı Kod Yaklaşımları ve Nedenleri

Proje sürecinde ilk olarak LDR benzeri bir yorumlama ile ham analog değer 1023’e bölünerek yüzde geçirgenlik hesaplanmaya çalışılmıştır. Bu yaklaşım, sensörün davranışı tam olarak anlaşılmadan geliştirildiği için başlangıçta pratik görünmüştür; ancak ilerleyen testlerde fiziksel gerçeklikle uyumsuz sonuçlar verdiği görülmüştür.

Özellikle karanlık durumda 1023 okunurken sistemin bunu yüksek geçirgenlik olarak

yorumlaması, modelin ters kurulduğunu açıkça ortaya koymuştur. Bazı erken sürümlerde absorbans değeri ek katsayılarla çarpılarak büyütülmüş, fakat bunun da standart spektrofotometrik tanımdan uzaklaştığı anlaşılmıştır.

Bir diğer sorun, DO çıkışı üzerinden geçirgenlik ve absorbans türetmeye çalışılmasıydı. Dijital veri yalnızca iki seviye üretmekteydi; bu nedenle nicel optik yorum yapmaya uygun değildi.

Yaklaşım | Kullanılan Mantık | Sorun | Sonuç
Doğrudan yüzdeleme | ham değer / 1023 | Sensör ters mantıklı olduğu için fiziksel yorumu bozdu | Terk edildi
DO ile hesaplama | 0/1 verisini ölçüme dönüştürme | Ara değer üretmedi; nicel ölçüme uygun değildi | Terk edildi
Katsayılı absorbans | log ifadesini ek katsayılarla büyütme | Standart absorbans tanımından uzaklaştı | Terk edildi
Dark-blank referanslı model | I_blank ve I_sample üzerinden T hesabı | Sensör davranışı ile uyum sağladı | Nihai yöntem olarak seçildi

Tablo 9. Proje sürecinde denenen kod yaklaşımları ve sınırlılıkları.

### 5.4. Arduino Yükleme ve Haberleşme Sorununun Giderilmesi

Yazılım geliştirme sürecinde yalnızca ölçüm formülleriyle ilgili değil, kart-programlayıcı haberleşmesiyle ilgili teknik problemler de yaşanmıştır. İlk yükleme

denemelerinde “protocol expects sync byte 0x14 but got 0x10”, “failed to initialise programmer” ve “initialization failed” benzeri hata mesajları alınmıştır.

Bu tür hatalar genellikle yanlış kart veya port seçimi, kablo problemleri, bootloader uyuşmazlığı ya da RX/TX pinlerindeki karışıklıklar nedeniyle ortaya çıkmaktadır. Sorunun çözümü için kart tipi ve port ayarları gözden geçirilmiş, bağlantılar sadeleştirilmiş ve boş bir test kodu ile iletişim yeniden doğrulanmıştır.

Sorun çözüldükten sonra kod yükleme ve seri monitör üzerinden veri akışı başarılı şekilde gerçekleşmiş, böylece yazılım geliştirme süreci normal akışına dönmüştür. Bu deneyim, prototip çalışmalarda donanım ve geliştirme ortamı uyumunun da en az algoritma kadar önemli olduğunu göstermiştir.

Hata Mesajı / Sorun | Olası Neden | Uygulanan Çözüm | Durum
protocol expects sync byte / init failed | Yanlış kart/port seçimi, bootloader veya bağlantı problemi | Kart ve port ayarları yeniden kontrol edildi; bağlantılar sadeleştirildi | Çözüldü
Analog değer yorumu tutarsızlığı | Sensörün ters mantıklı davranması | Dark ve blank referanslı modele geçildi | Çözüldü
DO ile ölçüm yetersizliği | Dijital çıkışın 0/1 seviyesinde kalması | AO hattı kullanıldı | Çözüldü
Blank absorbansının sıfıra yaklaşmaması | Yanlış formül veya referans seçimi | blankRaw deneysel olarak belirlendi ve yazılım güncellendi | Çözüldü

Tablo 10. Karşılaşılan hata mesajları ve çözüm adımları.

### 5.5. Dark ve Blank Referanslı Nihai Hesaplama Modeli

Nihai modelde ham analog değerler doğrudan geçirgenlik olarak yorumlanmamıştır. Bunun yerine önce blank ve örneğe karşılık gelen göreli ışık büyüklükleri tanımlanmıştır. Bu adım, sensörün ters karakteristiği nedeniyle zorunlu olmuştur.

Modelde I_blank = darkRaw - blankRaw ve I_sample = darkRaw - rawValue olarak tanımlanmıştır. Daha sonra T = I_sample / I_blank hesabı yapılarak geçirgenlik bulunmuş; absorbans ise A = -log10(T) ile hesaplanmıştır. Böylece blank durumunda T’nin 1’e, absorbansın ise sıfıra yaklaşması sağlanmıştır.

Bu yaklaşımın doğruluğu, blank testlerinde absorbansın 0’a çok yakın çıkması ile deneysel olarak desteklenmiştir. Sonuç olarak dark ve blank referanslı model, proje için nihai hesaplama çatısı olarak kabul edilmiştir.

Değişken | Yazılımdaki Rolü | Fiziksel Karşılığı
darkRaw | Karanlık referans sabiti | Sistemin karanlıkta verdiği maksimum ham değer
blankRaw | Blank referans sabiti | Boş küvette aydınlık durumda okunan referans değer
rawValue | Anlık okuma | Örneğin mevcut ham sensör değeri
I_blank | Referans ışık büyüklüğü | Dark ile blank arasındaki fark
I_sample | Örnek ışık büyüklüğü | Dark ile mevcut örnek okuması arasındaki fark
transmittance | Geçirgenlik | Örnekten geçen ışığın referansa oranı
absorbance | Absorbans | Örneğin soğurma büyüklüğü
sampleCount | Ortalama örnek sayısı | Ölçüm kararlılığını artırır

Tablo 11. Nihai algoritmada kullanılan değişkenler ve fiziksel karşılıkları.

### 5.6. Nihai Kod Yapısı

Nihai kod, sensörün AO hattından alınan ham veriyi kullanarak önce I_blank ve I_sample büyüklüklerini hesaplamakta, ardından geçirgenlik ve absorbans değerlerini üretmektedir. Sistemin fiziksel yorumu bu ara büyüklükler üzerinden sağlandığı için kodun merkezinde referans mantığı yer almaktadır.

Dark referansı 1023, blank referansı ise deneysel ölçümler sonucunda 200 olarak belirlenmiştir. Bu iki sabit sayesinde ham değer doğrudan fiziksel anlam taşımayan bir sayı olmaktan çıkmış, göreli ışık geçişini temsil eden bir büyüklüğe dönüştürülmüştür.

Ayrıca ölçüm kararlılığını artırmak için tek anlık değer yerine belirli sayıda örnek okunmakta ve average absorbance değeri hesaplanmaktadır. sampleCount değerinin 10 yapılması, sonuçların çok dalgalanmadan izlenmesini sağlamıştır.


Şekil 7. Nihai Arduino ölçüm ve hesaplama kodu ekran görüntüsü.

### 5.7. Nihai Kodun Satır Bazlı Açıklaması - Bölüm 1

Kodun başında sensorPin değişkeni A0 olarak tanımlanmakta ve sampleCount değeri ortalama alma işlemi için sabitlenmektedir. Bu iki parametre, sistemin giriş kanalını ve kararlılık davranışını belirleyen temel ayarlardır.

Ardından darkRaw ve blankRaw sabitleri tanımlanır. Bunlar deneysel testlerden elde edildiği için kodun fiziksel dünyaya bağlandığı kritik noktalardır. Eğer bu iki değer yanlış seçilirse, hesaplama matematiksel olarak çalışsa bile fiziksel yorum hatalı olur.

rawValue, transmittance, absorbance, totalAbsorbance ve averageAbsorbance gibi değişkenler ölçüm döngüsü boyunca anlık ve ortalama sonuçları taşır. totalAbsorbance değişkeni, sampleCount kadar ölçüm biriktiğinde ortalama üretmek için kullanılır.

Kod Bölümü | Ne Yapar?
const int sensorPin = A0; | AO hattının bağlandığı analog giriş pinini belirler
const int sampleCount = 10; | Kaç ölçümün ortalamasının alınacağını belirler
const float darkRaw = 1023.0; | Dark referansını sabitler
const float blankRaw = 200.0; | Blank referansını sabitler
float ... | Ham veri, geçirgenlik ve absorbans için

değişkenleri tanımlar

Tablo 11A. Nihai kodun ilk bölümündeki temel tanımlar.

### 5.8. Nihai Kodun Satır Bazlı Açıklaması - Bölüm 2

loop() fonksiyonu içerisinde önce rawValue = analogRead(sensorPin) komutu ile sensörden anlık veri alınır. Daha sonra I_blank ve I_sample büyüklükleri hesaplanır. Bu büyüklükler sırasıyla referans ve örneğe karşılık gelen göreli ışık değeridir.

Algoritma, fiziksel olarak anlamsız veya matematiksel olarak logaritmayı bozacak durumlara karşı koruma sınırları da içerir. Örneğin transmittance değeri çok küçük olduğunda

ya da 1’den büyük olduğunda sınırlandırılır. Böylece yazılım kararlı kalır ve sonuçların okunabilirliği korunur.

Ölçüm sayısı sampleCount değerine ulaştığında averageAbsorbance hesaplanır ve seri

monitöre yazdırılır. Bu tasarım, anlık dalgalanmaların etkisini azaltır ve deney sırasında daha güvenilir bir çıktı izlenmesini sağlar.

Kod Bölümü | Ne Yapar?
analogRead(sensorPin) | Sensörden ham analog veriyi alır
I_blank ve I_sample hesapları | Referans ve örnek ışık büyüklüklerini kurar
transmittance = I_sample / I_blank | Geçirgenliği hesaplar
absorbance = -log10(transmittance) | Absorbansı hesaplar
averageAbsorbance | Çoklu ölçümlerin ortalamasını verir

Tablo 11B. Nihai kodun döngü kısmındaki işlem sırası.

### 6. YAPILAN TESTLER VE ELDE EDİLEN SONUÇLAR

Vize aşamasına kadar sistemin doğru çalışma mantığını doğrulamak amacıyla bir dizi test gerçekleştirilmiştir. Bu testlerde sensörün analog veri verip vermediği, ışığa tepki davranışı, karanlık referansı, boş küvet referansı ve yazılım hesaplamalarının tutarlılığı incelenmiştir.

Aşağıda yer alan her test bölümü, yalnızca sonucu değil; testin neden yapıldığını, hangi fiziksel soruyu yanıtladığını ve projedeki hangi karara temel oluşturduğunu açıklamaktadır.
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

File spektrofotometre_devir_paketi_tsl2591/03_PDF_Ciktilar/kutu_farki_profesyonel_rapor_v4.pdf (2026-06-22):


Sayfa 1

# SPEKTROFOTOMETRE PROTOTİPİ

## Yeni 3D Baskı Kutu Tasarımının Ölçüm Kararlılığına Etkisi

Teknik Durum ve Karşılaştırma Raporu

Proje | Arduino Tabanlı Düşük Maliyetli Spektrofotometre Tasarımı
Hazırlayan | Samet Kılıç
Rapor türü | Kutu farkı ve optik kararlılık değerlendirmesi
Tarih | (güncellenecek)

Dark
≈1023

ışık kapalı, kutu kapalı

Blank
≈13

ışık açık, boş küvet

Sonuç

## daha stabil

daha kontrollü optik geometri
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

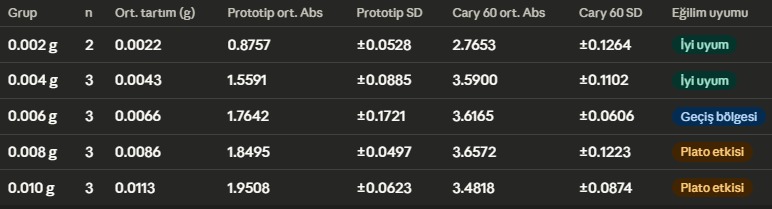
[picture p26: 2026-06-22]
spektrofotometre_devir_paketi_tsl2591/04_Gorseller/olcumler2.jpeg

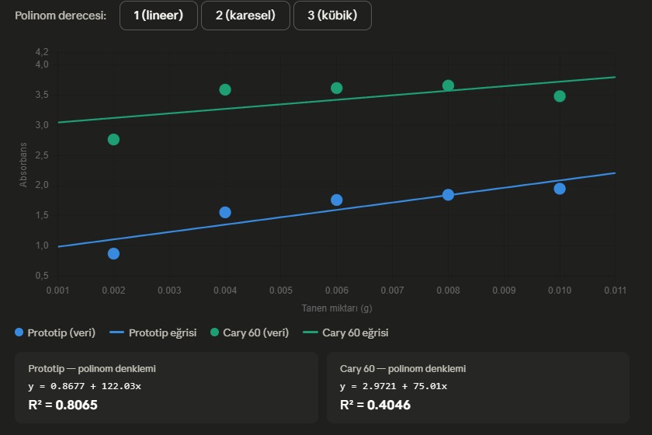
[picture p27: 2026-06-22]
spektrofotometre_devir_paketi_tsl2591/04_Gorseller/lineer.jpeg

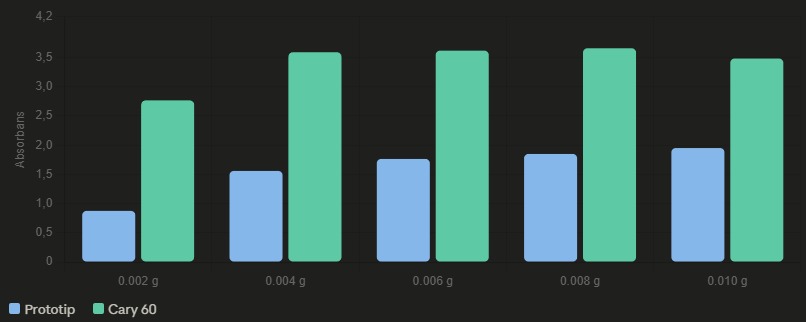
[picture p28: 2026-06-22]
spektrofotometre_devir_paketi_tsl2591/04_Gorseller/prototipvecarykarşılaştırma.jpeg

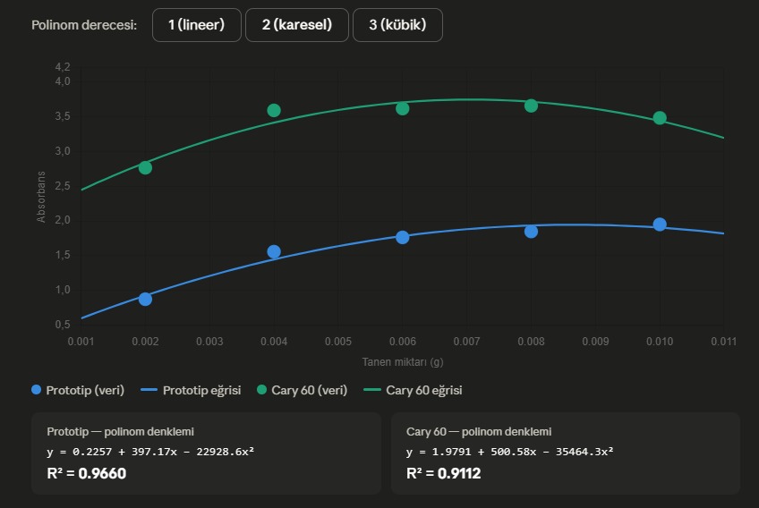
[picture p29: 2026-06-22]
spektrofotometre_devir_paketi_tsl2591/04_Gorseller/karesel.jpeg

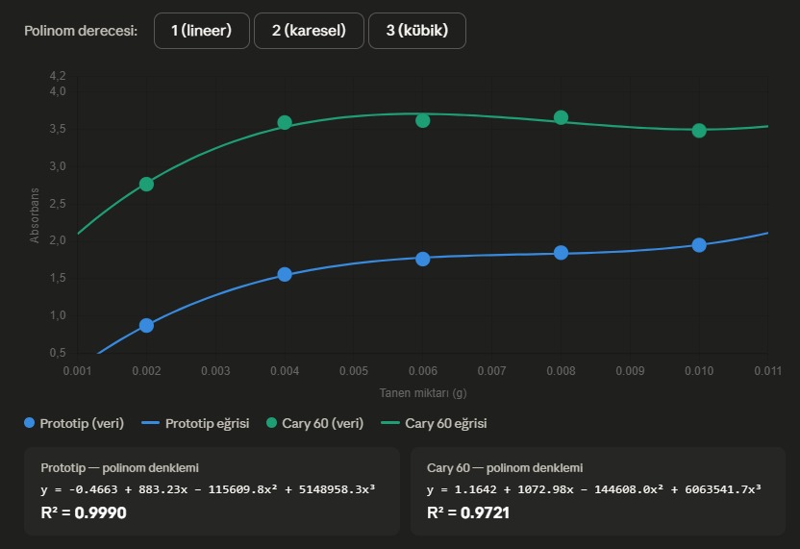
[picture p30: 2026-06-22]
spektrofotometre_devir_paketi_tsl2591/04_Gorseller/kübik.jpeg

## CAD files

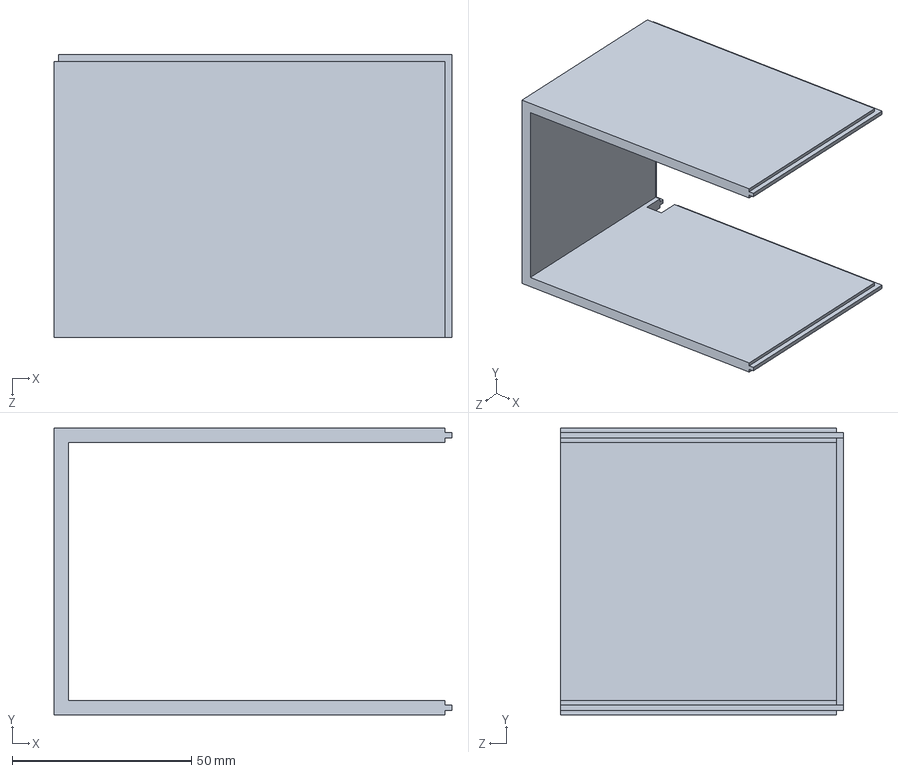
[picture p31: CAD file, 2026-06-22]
spektrofotometre_devir_paketi_tsl2591/05_3D_Model_ve_Kutu/ikinci/Duvar 1.SLDPRT
111.0 x 80.0 x 79.0 mm

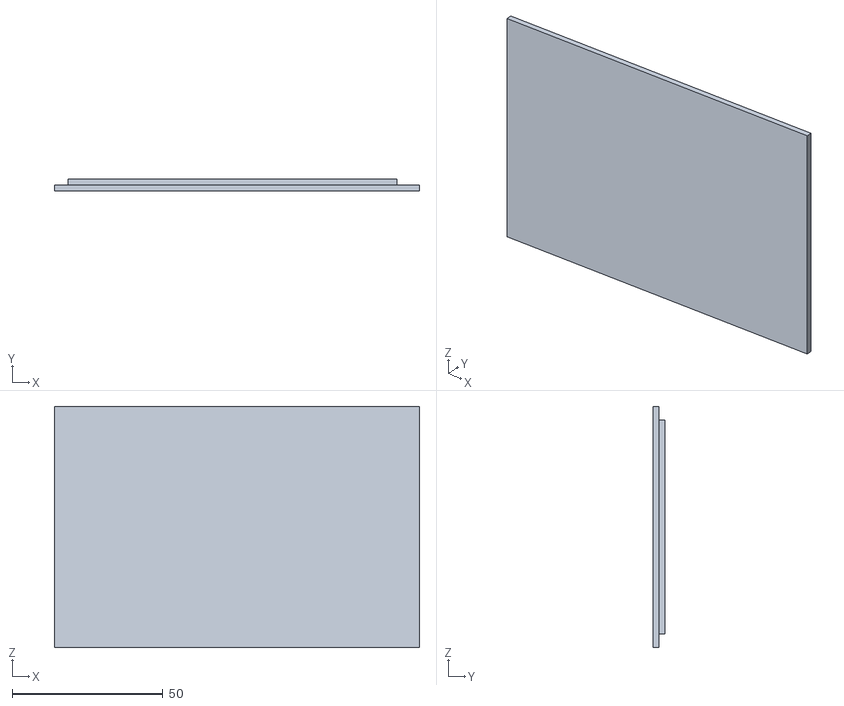
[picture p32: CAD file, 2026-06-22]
spektrofotometre_devir_paketi_tsl2591/05_3D_Model_ve_Kutu/ilk/Kapak.STL
121.0 x 4.00 x 80.0

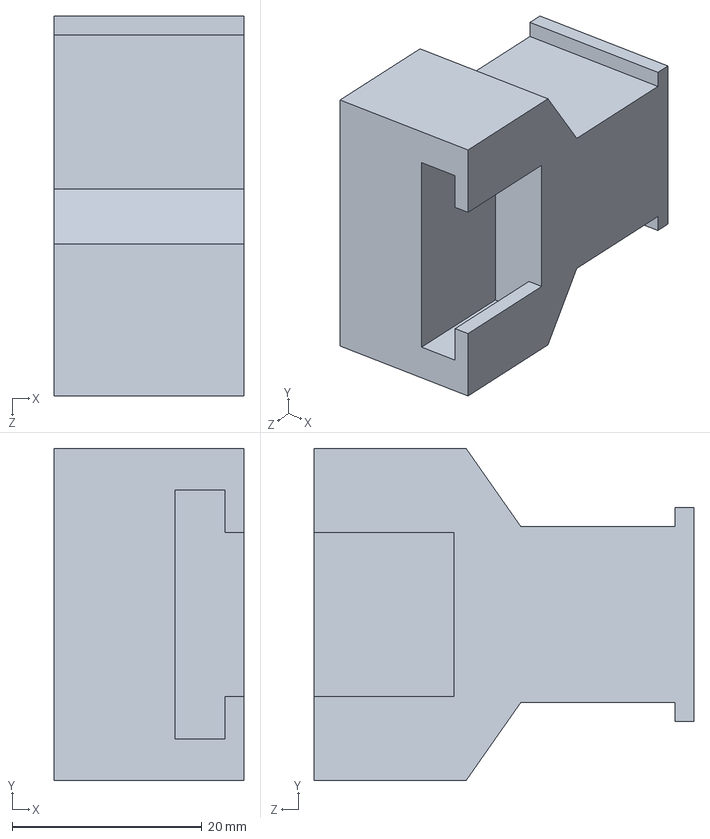
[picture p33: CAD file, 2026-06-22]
spektrofotometre_devir_paketi_tsl2591/05_3D_Model_ve_Kutu/ikinci/Sensör - 2.SLDPRT
20.0 x 35.0 x 40.0 mm

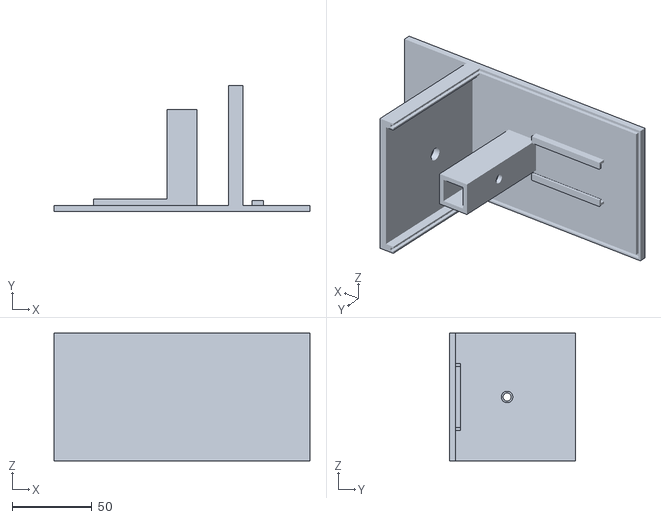
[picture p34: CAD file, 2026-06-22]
spektrofotometre_devir_paketi_tsl2591/05_3D_Model_ve_Kutu/ilk/Kutu.STL
160.0 x 79.0 x 80.0

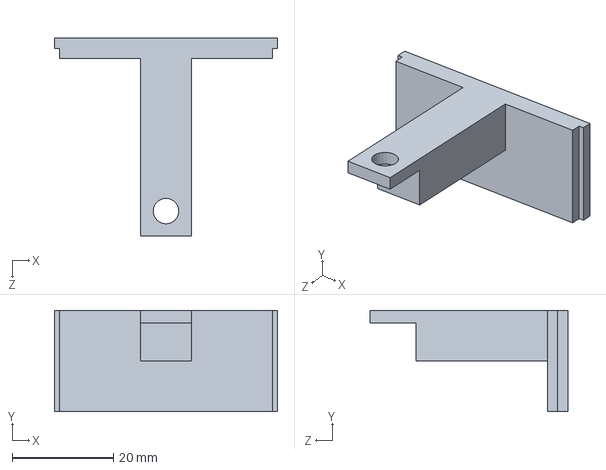
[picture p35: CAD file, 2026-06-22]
spektrofotometre_devir_paketi_tsl2591/05_3D_Model_ve_Kutu/ikinci/Kaynak 2.SLDPRT
44.0 x 20.0 x 39.0 mm

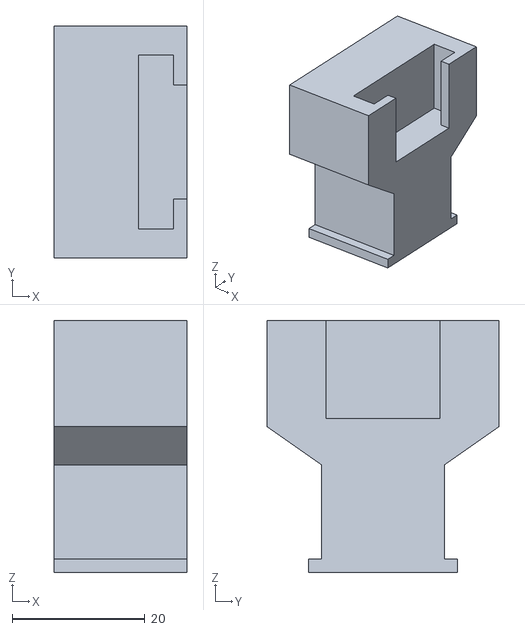
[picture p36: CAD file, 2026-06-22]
spektrofotometre_devir_paketi_tsl2591/05_3D_Model_ve_Kutu/ilk/Sensör - 2.STL
20.0 x 35.0 x 38.0

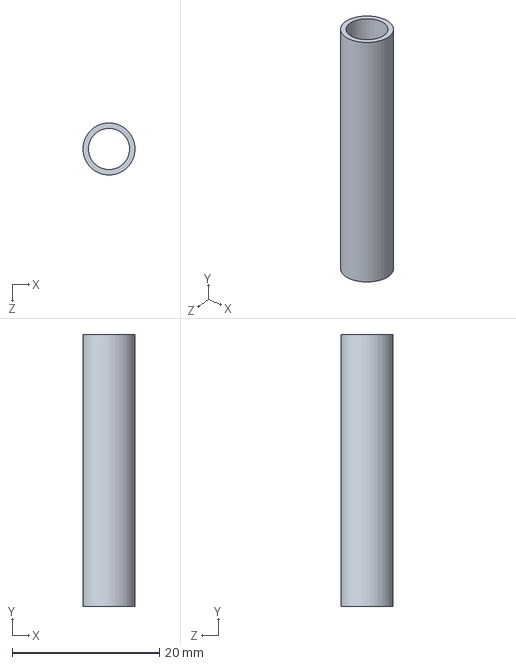
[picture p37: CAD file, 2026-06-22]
spektrofotometre_devir_paketi_tsl2591/05_3D_Model_ve_Kutu/ikinci/silindir.SLDPRT
7.09 x 37.0 x 7.10 mm

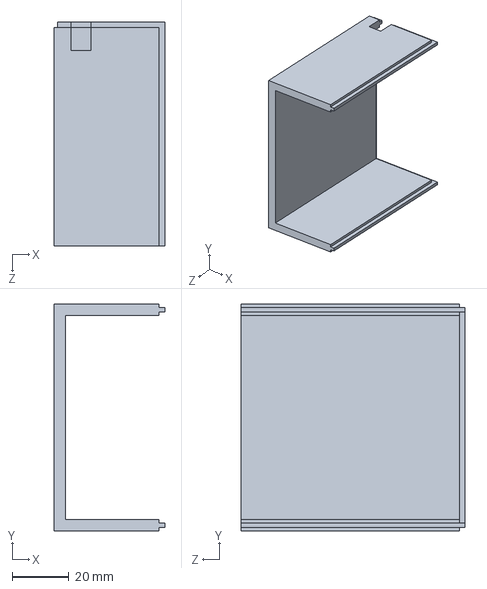
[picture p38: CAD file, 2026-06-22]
spektrofotometre_devir_paketi_tsl2591/05_3D_Model_ve_Kutu/ikinci/Duvar 2.SLDPRT
39.0 x 80.0 x 79.0 mm

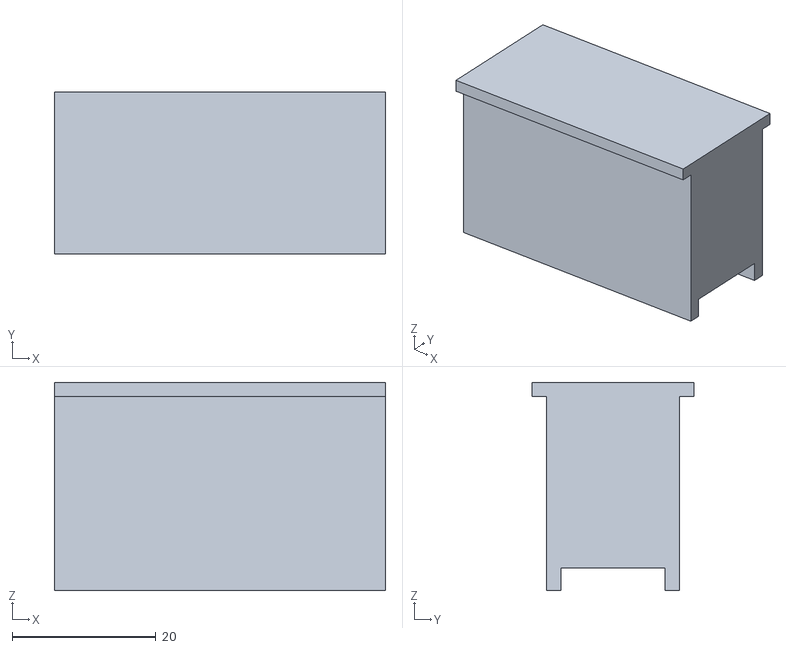
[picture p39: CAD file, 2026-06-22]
spektrofotometre_devir_paketi_tsl2591/05_3D_Model_ve_Kutu/ilk/Sensör - 1.STL
46.0 x 22.5 x 29.0

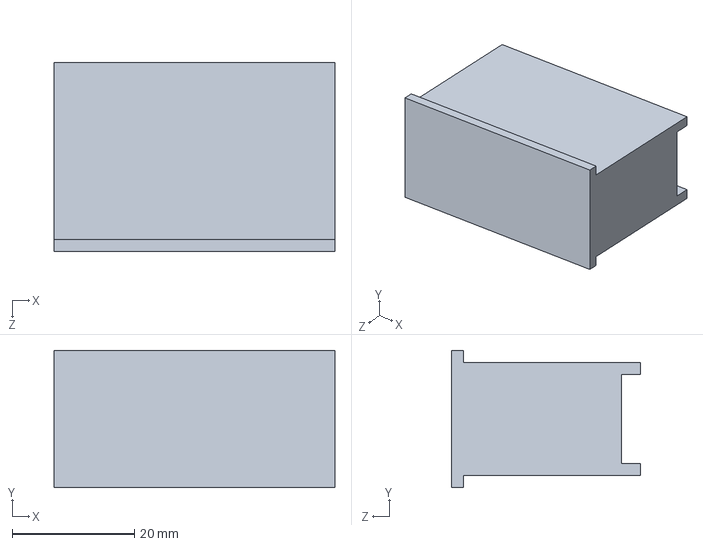
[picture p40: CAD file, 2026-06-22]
spektrofotometre_devir_paketi_tsl2591/05_3D_Model_ve_Kutu/ikinci/Sensör - 1.SLDPRT
46.0 x 22.5 x 31.0 mm

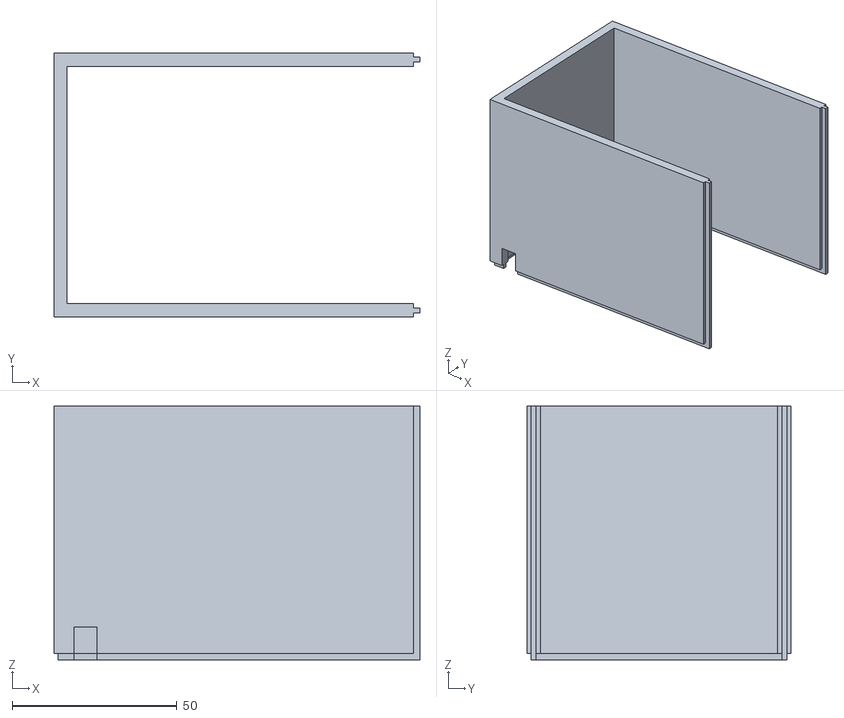
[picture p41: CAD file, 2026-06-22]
spektrofotometre_devir_paketi_tsl2591/05_3D_Model_ve_Kutu/ilk/Duvar.STL
111.0 x 80.0 x 77.0

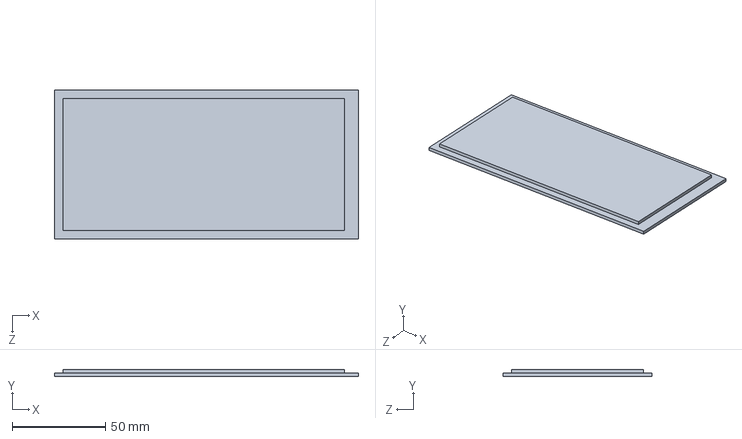
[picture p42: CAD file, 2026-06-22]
spektrofotometre_devir_paketi_tsl2591/05_3D_Model_ve_Kutu/ikinci/Kapak1.SLDPRT
163.0 x 4.00 x 80.0 mm

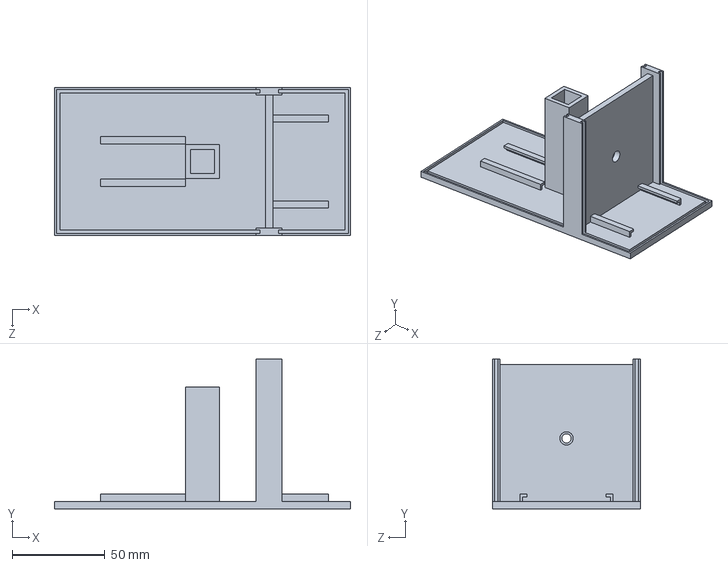
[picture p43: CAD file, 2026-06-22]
spektrofotometre_devir_paketi_tsl2591/05_3D_Model_ve_Kutu/ikinci/Gövde.SLDPRT
160.0 x 81.0 x 80.0 mm

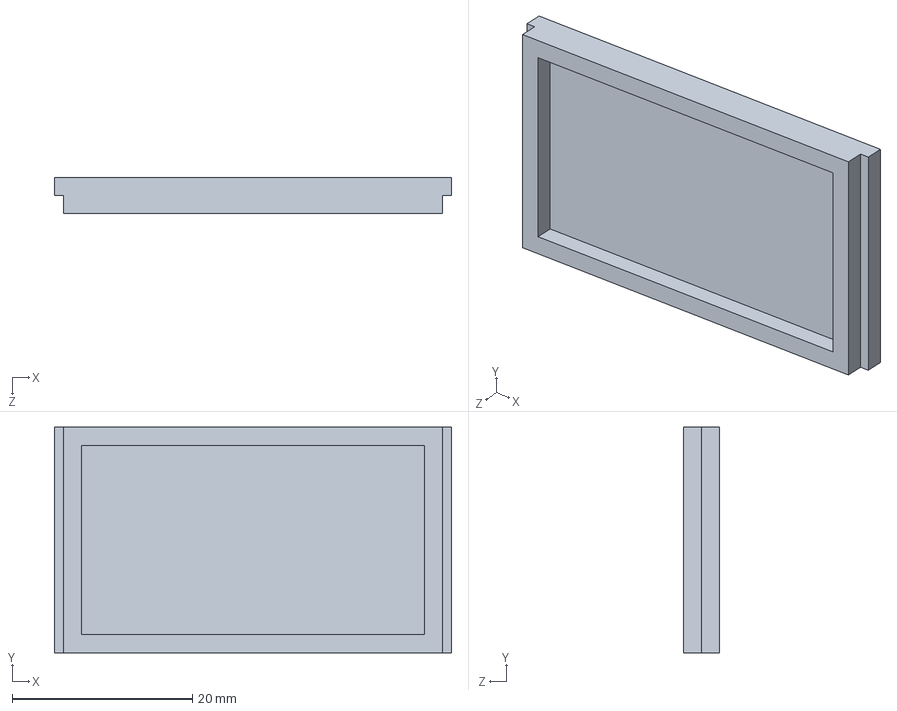
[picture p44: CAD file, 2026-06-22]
spektrofotometre_devir_paketi_tsl2591/05_3D_Model_ve_Kutu/ikinci/Kaynak 1,.SLDPRT
44.0 x 25.0 x 4.00 mm

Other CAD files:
spektrofotometre_devir_paketi_tsl2591/05_3D_Model_ve_Kutu/ilk/silindir.STL
spektrofotometre_devir_paketi_tsl2591/05_3D_Model_ve_Kutu/ikinci/Duvar 1.STL
spektrofotometre_devir_paketi_tsl2591/05_3D_Model_ve_Kutu/ikinci/Duvar 2.STL
spektrofotometre_devir_paketi_tsl2591/05_3D_Model_ve_Kutu/ikinci/Gövde.STL
spektrofotometre_devir_paketi_tsl2591/05_3D_Model_ve_Kutu/ikinci/Kapak1.STL
spektrofotometre_devir_paketi_tsl2591/05_3D_Model_ve_Kutu/ikinci/Kaynak 1,.STL
spektrofotometre_devir_paketi_tsl2591/05_3D_Model_ve_Kutu/ikinci/Kaynak 2.STL
spektrofotometre_devir_paketi_tsl2591/05_3D_Model_ve_Kutu/ikinci/Sensör - 1.STL
spektrofotometre_devir_paketi_tsl2591/05_3D_Model_ve_Kutu/ikinci/Sensör - 2.STL
spektrofotometre_devir_paketi_tsl2591/05_3D_Model_ve_Kutu/ikinci/silindir.STL

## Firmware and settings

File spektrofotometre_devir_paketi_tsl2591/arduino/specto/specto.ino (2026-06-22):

// =======================================================
// ARDUINO TABANLI SPEKTROFOTOMETRE FINAL INO KODU
// Sensör: TSL2591 dijital ışık sensörü
// Web Panel: Python / Flask app.py ile uyumlu
//
// Bu kodun görevi:
// 1. TSL2591 sensöründen görünür ışık değerini okumak
// 2. Dark ve Blank referanslarını komutla güncellemek
// 3. Transmittance ve Absorbance hesaplamak
// 4. Sonuçları seri porttan Flask web paneline göndermek
//
// Web panelden gelen komutlar:
// SET_DARK   : Işık kapalı + kutu kapalı iken darkRaw alır
// SET_BLANK  : Işık açık + kör/blank küvet varken blankRaw alır
// GET_REF    : Mevcut darkRaw ve blankRaw değerlerini gönderir
// RESET_AVG  : Ortalama hesaplama tamponunu sıfırlar
// =======================================================


// I2C haberleşmesi için gerekli kütüphane.
// TSL2591 sensörü Arduino UNO'da SDA=A4, SCL=A5 üzerinden haberleşir.
#include <Wire.h>

// Adafruit sensör altyapısı için kullanılan genel sensör kütüphanesi.
#include <Adafruit_Sensor.h>

// TSL2591 dijital ışık sensörünü kullanmak için gerekli kütüphane.
#include <Adafruit_TSL2591.h>

// log10() fonksiyonunu kullanmak için matematik kütüphanesi.
#include <math.h>


// TSL2591 sensör nesnesi oluşturulur.
// 2591 burada sensör ID değeri gibi kullanılır.
Adafruit_TSL2591 tsl = Adafruit_TSL2591(2591);


// =======================================================
// ÖLÇÜM AYARLARI
// =======================================================

// Ortalama almak için kaç ölçüm yapılacağını belirler.
// 10 ölçüm alınır, ortalaması hesaplanır ve web panele gönderilir.
const int sampleCount = 10;

// Dark veya blank alma sırasında kaç ölçüm alınacağını belirler.
// Daha yüksek sayı daha kararlı referans sağlar.
const int calibrationSampleCount = 20;

// Normal ölçümler arasında bekleme süresi.
// 200 ms x 10 ölçüm = yaklaşık 2 saniyede bir DATA gönderilir.
const int sampleDelayMs = 200;

// Dark/blank kalibrasyon ölçümleri arasındaki bekleme süresi.
const int calibrationDelayMs = 100;


// =======================================================
// REFERANS DEĞERLER
// =======================================================

// Dark Raw:
// Işık kapalı + kutu kapalı iken sensörün okuduğu taban değerdir.
// Web panelden SET_DARK komutu ile güncellenir.
float darkRaw = 0.7;

// Blank Raw:
// Işık açık + kör/blank küvet + kutu kapalı iken sensörün okuduğu referans değerdir.
// Başlangıçta eski ölçüm değeri yazılıdır.
// Web panelden SET_BLANK komutu ile güncellenir.
float blankRaw = 965.0;


// =======================================================
// ANLIK ÖLÇÜM DEĞİŞKENLERİ
// =======================================================

// Sensörden okunan anlık görünür ışık değeri.
float rawValue = 0.0;

// Anlık transmittance/geçirgenlik değeri.
// Hesaplamada 0-1 arasıdır, gönderirken yüzdeye çevrilir.
float transmittance = 0.0;

// Anlık absorbans değeri.
float absorbance = 0.0;


// =======================================================
// ORTALAMA HESAPLAMA DEĞİŞKENLERİ
// =======================================================

// Ortalama Raw Visible için toplam değer.
float totalRaw = 0.0;

// Ortalama transmittance için toplam değer.
float totalTransmittance = 0.0;

// Ortalama absorbance için toplam değer.
float totalAbsorbance = 0.0;

// Kaç ölçüm alındığını takip eden sayaç.
int readIndex = 0;

// Ortalama Raw Visible değeri.
float averageRaw = 0.0;

// Ortalama Transmittance değeri.
float averageTransmittance = 0.0;

// Ortalama Absorbance değeri.
float averageAbsorbance = 0.0;


// =======================================================
// KALİBRASYON DURUM BİLGİLERİ
// =======================================================

// Dark alma işleminin yapılıp yapılmadığını takip eder.
bool darkCalibrated = false;

// Blank alma işleminin yapılıp yapılmadığını takip eder.
bool blankCalibrated = false;


// =======================================================
// SETUP FONKSİYONU
// Arduino ilk açıldığında yalnızca bir kez çalışır.
// =======================================================
void setup() {

  // Seri haberleşme başlatılır.
  // Python/Flask tarafında da baud 9600 olmalıdır.
  Serial.begin(9600);

  // Seri portun oturması için kısa bekleme yapılır.
  delay(1000);

  // TSL2591 sensörü başlatılır.
  // Sensör bulunamazsa hata mesajı verilir.
  if (!tsl.begin()) {

    // Web panel bu hatayı okuyabilir.
    Serial.println("ERROR,TSL2591_NOT_FOUND");

    // Sensör bulunamazsa sistem burada durur.
    while (1) {
      delay(1000);
    }
  }

  // Sensör düşük kazanca alınır.
  // Güçlü ışıkta doygunluğu azaltır.
  tsl.setGain(TSL2591_GAIN_LOW);

  // Ölçüm süresi 100 ms yapılır.
  // Kısa entegrasyon daha hızlı tepki verir.
  tsl.setTiming(TSL2591_INTEGRATIONTIME_100MS);

  // Arduino'nun hazır olduğunu web panele bildirir.
  Serial.println("READY,TSL2591_OK");

  // Başlangıç dark ve blank değerleri web panele / Serial Monitor'e gönderilir.
  Serial.print("STATUS,REF,DARK=");
  Serial.print(darkRaw, 2);
  Serial.print(",BLANK=");
  Serial.println(blankRaw, 2);
}


// =======================================================
// LOOP FONKSİYONU
// Arduino açık kaldığı sürece sürekli çalışır.
// =======================================================
void loop() {

  // Web panelden veya Serial Monitor'den komut gelmiş mi kontrol eder.
  // SET_DARK, SET_BLANK, GET_REF, RESET_AVG komutları burada işlenir.
  handleSerialCommands();

  // TSL2591 sensöründen anlık görünür ışık değeri okunur.
  rawValue = readVisibleValue();

  // Kör/blank referansından dark değeri çıkarılır.
  // Böylece referans ışık değeri elde edilir.
  float I_blank = blankRaw - darkRaw;

  // Numune ölçümünden dark değeri çıkarılır.
  // Böylece numuneden geçen net ışık değeri elde edilir.
  float I_sample = rawValue - darkRaw;

  // Blank referansı geçersizse hesaplama yapılamaz.
  // Örneğin blankRaw darkRaw'dan küçük/eşitse bu hata oluşur.
  if (I_blank <= 0.0001) {
    Serial.println("ERROR,INVALID_REFERENCE");
    delay(1000);
    return;
  }

  // Numuneden geçen ışık sıfırdan küçük çıkarsa çok küçük değere sabitlenir.
  // Bu işlem log10 hesabında matematiksel hata oluşmasını engeller.
  if (I_sample < 0.0001) {
    I_sample = 0.0001;
  }

  // Transmittance hesaplanır.
  // T = I_sample / I_blank
  // Yani numuneden geçen ışığın körden geçen ışığa oranıdır.
  transmittance = I_sample / I_blank;

  // Transmittance çok küçükse minimum değere sabitlenir.
  // Böylece absorbans sonsuza gitmez.
  if (transmittance < 0.0001) {
    transmittance = 0.0001;
  }

  // Transmittance 1'den büyükse 1'e sabitlenir.
  // Çünkü numune teorik olarak körden daha fazla ışık geçirirse absorbans negatif çıkabilir.
  if (transmittance > 1.0) {
    transmittance = 1.0;
  }

  // Absorbans hesaplanır.
  // A = -log10(T)
  // T azalırsa absorbans artar.
  absorbance = -log10(transmittance);

  // Ortalama hesaplamak için anlık Raw değeri toplam değere eklenir.
  totalRaw += rawValue;

  // Ortalama hesaplamak için anlık transmittance toplam değere eklenir.
  totalTransmittance += transmittance;

  // Ortalama hesaplamak için anlık absorbans toplam değere eklenir.
  totalAbsorbance += absorbance;

  // Ölçüm sayacı 1 artırılır.
  readIndex++;

  // Bir sonraki ölçümden önce kısa bekleme yapılır.
  delay(sampleDelayMs);

  // Belirlenen ölçüm sayısına ulaşıldığında ortalama hesaplanır.
  if (readIndex >= sampleCount) {

    // Ortalama Raw Visible hesaplanır.
    averageRaw = totalRaw / sampleCount;

    // Ortalama Transmittance hesaplanır.
    averageTransmittance = totalTransmittance / sampleCount;

    // Ortalama Absorbance hesaplanır.
    averageAbsorbance = totalAbsorbance / sampleCount;

    // Flask web panelin okuyacağı veri satırı gönderilir.
    // Son app.py hem 5 alanlı hem de 7 alanlı DATA formatını destekliyor.
    //
    // Format:
    // DATA,AverageRaw,AverageTransmittancePercent,Absorbance,AverageAbsorbance,DarkRaw,BlankRaw
    //
    // Örnek:
    // DATA,55.70,5.70,1.2415,1.2439,0.70,379.70
    Serial.print("DATA,");

    // Ortalama ham görünür ışık değeri gönderilir.
    Serial.print(averageRaw, 2);
    Serial.print(",");

    // Ortalama transmittance yüzde olarak gönderilir.
    Serial.print(averageTransmittance * 100.0, 2);
    Serial.print(",");

    // Son hesaplanan anlık absorbans gönderilir.
    Serial.print(absorbance, 4);
    Serial.print(",");

    // Ortalama absorbans gönderilir.
    Serial.print(averageAbsorbance, 4);
    Serial.print(",");

    // Mevcut darkRaw değeri gönderilir.
    Serial.print(darkRaw, 2);
    Serial.print(",");

    // Mevcut blankRaw değeri gönderilir.
    Serial.println(blankRaw, 2);

    // Ortalama hesaplama toplamları sıfırlanır.
    totalRaw = 0.0;

    // Transmittance toplamı sıfırlanır.
    totalTransmittance = 0.0;

    // Absorbance toplamı sıfırlanır.
    totalAbsorbance = 0.0;

    // Ölçüm sayacı sıfırlanır.
    readIndex = 0;
  }
}


// =======================================================
// GÖRÜNÜR IŞIK OKUMA FONKSİYONU
// TSL2591 sensöründen full ve IR değerlerini alır.
// Görünür ışık = full - IR olarak hesaplanır.
// =======================================================
float readVisibleValue() {

  // Sensörden 32 bit toplam luminosity değeri alınır.
  uint32_t lum = tsl.getFullLuminosity();

  // Üst 16 bit IR yani kızılötesi değeridir.
  uint16_t ir = lum >> 16;

  // Alt 16 bit full spectrum yani toplam ışık değeridir.
  uint16_t full = lum & 0xFFFF;

  // Görünür ışık değeri hesaplanır.
  float visible = (float)full - (float)ir;

  // Eğer hesaplama negatif çıkarsa sıfıra çekilir.
  if (visible < 0) {
    visible = 0;
  }

  // Görünür ışık değeri geri döndürülür.
  return visible;
}


// =======================================================
// ORTALAMA GÖRÜNÜR IŞIK OKUMA FONKSİYONU
// Dark ve blank alma sırasında kullanılır.
// Birden fazla okuma yapıp ortalamasını döndürür.
// =======================================================
float readAverageVisible(int count) {

  // Okunan değerlerin toplamı.
  float sum = 0.0;

  // İstenen ölçüm sayısı kadar döngü çalışır.
  for (int i = 0; i < count; i++) {

    // Görünür ışık değeri okunup toplam değere eklenir.
    sum += readVisibleValue();

    // Ölçümler arasında kısa bekleme yapılır.
    delay(calibrationDelayMs);
  }

  // Ortalama değer hesaplanır.
  float avg = sum / count;

  // Ortalama değer döndürülür.
  return avg;
}


// =======================================================
// SERİ PORT KOMUTLARINI İŞLEYEN FONKSİYON
// Web panel Arduino'ya komutları seri porttan gönderir.
// Bu fonksiyon o komutları okuyup gerekli işlemi yapar.
// =======================================================
void handleSerialCommands() {

  // Seri portta veri yoksa fonksiyondan çıkılır.
  if (!Serial.available()) {
    return;
  }

  // Satır sonuna kadar gelen komut okunur.
  String command = Serial.readStringUntil('\n');

  // Komutun başındaki ve sonundaki boşluklar temizlenir.
  command.trim();

  // Komut büyük harfe çevrilir.
  // Böylece set_blank veya SET_BLANK yazılması fark etmez.
  command.toUpperCase();

  // -------------------------------------------------------
  // SET_DARK KOMUTU
  // Işık kapalı + kutu kapalı durumdayken kullanılmalıdır.
  // -------------------------------------------------------
  if (command == "SET_DARK") {

    // Önce ortalama tamponları sıfırlanır.
    resetAverages();

    // O anki karanlık değeri çoklu ölçümle alınır.
    darkRaw = readAverageVisible(calibrationSampleCount);

    // Dark kalibrasyon yapıldı bilgisi tutulur.
    darkCalibrated = true;

    // Web panele yeni dark değeri bildirilir.
    Serial.print("STATUS,DARK_SET,");
    Serial.println(darkRaw, 2);
  }

  // -------------------------------------------------------
  // SET_BLANK KOMUTU
  // Işık açık + kör/blank küvet takılı + kutu kapalı durumdayken kullanılmalıdır.
  // -------------------------------------------------------
  else if (command == "SET_BLANK") {

    // Önce ortalama tamponları sıfırlanır.
    resetAverages();

    // O anki blank değeri çoklu ölçümle alınır.
    blankRaw = readAverageVisible(calibrationSampleCount);

    // Blank kalibrasyon yapıldı bilgisi tutulur.
    blankCalibrated = true;

    // Web panele yeni blank değeri bildirilir.
    Serial.print("STATUS,BLANK_SET,");
    Serial.println(blankRaw, 2);
  }

  // -------------------------------------------------------
  // GET_REF KOMUTU
  // Mevcut darkRaw ve blankRaw değerlerini gösterir.
  // -------------------------------------------------------
  else if (command == "GET_REF") {

    // Referans değerleri web panele / Serial Monitor'e gönderilir.
    Serial.print("STATUS,REF,DARK=");
    Serial.print(darkRaw, 2);
    Serial.print(",BLANK=");
    Serial.println(blankRaw, 2);
  }

  // -------------------------------------------------------
  // RESET_AVG KOMUTU
  // Ortalama hesaplama tamponlarını sıfırlar.
  // Numune değişiminden sonra kullanılabilir.
  // -------------------------------------------------------
  else if (command == "RESET_AVG") {

    // Ortalama tamponları sıfırlanır.
    resetAverages();

    // Web panele bilgi mesajı gönderilir.
    Serial.println("STATUS,AVERAGE_RESET");
  }

  // -------------------------------------------------------
  // Tanınmayan komut gelirse hata mesajı gönderilir.
  // -------------------------------------------------------
  else {

    // Komut bilinmiyorsa hata olarak yazdırılır.
    Serial.print("ERROR,UNKNOWN_COMMAND,");
    Serial.println(command);
  }
}


// =======================================================
// ORTALAMA TAMPONLARINI SIFIRLAMA FONKSİYONU
// Dark/blank alma öncesinde veya numune değişiminde kullanılır.
// =======================================================
void resetAverages() {

  // Raw toplamı sıfırlanır.
  totalRaw = 0.0;

  // Transmittance toplamı sıfırlanır.
  totalTransmittance = 0.0;

  // Absorbance toplamı sıfırlanır.
  totalAbsorbance = 0.0;

  // Ölçüm sayacı sıfırlanır.
  readIndex = 0;

  // Ortalama Raw değeri sıfırlanır.
  averageRaw = 0.0;

  // Ortalama Transmittance değeri sıfırlanır.
  averageTransmittance = 0.0;

  // Ortalama Absorbance değeri sıfırlanır.
  averageAbsorbance = 0.0;
}

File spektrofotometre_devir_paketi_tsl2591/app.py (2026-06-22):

import csv
import os
import threading
import time
from datetime import datetime

import serial
from flask import Flask, jsonify, request, send_file, Response

# =========================================================
# SPEKTROFOTOMETRE WEB PANELİ - TSL2591
# Arduino seri port çıktısı şu formatta olmalı:
# Eski format desteklenir:
# DATA,RawVisible,Transmittance,Absorbance,AverageAbsorbance
# Yeni önerilen format desteklenir:
# DATA,RawVisible,Transmittance,Absorbance,AverageAbsorbance,DarkRaw,BlankRaw
# Komutlar:
# SET_DARK   -> ışık kapalı + kutu kapalı iken darkRaw alır
# SET_BLANK  -> ışık açık + kör/blank küvet varken blankRaw alır
# GET_REF    -> Arduino'daki darkRaw ve blankRaw değerlerini ister
# RESET_AVG  -> Arduino ortalama tamponlarını sıfırlar
# =========================================================

PORT = "COM6"       # Arduino hangi COM porttaysa burayı değiştir
BAUD = 9600

RUN_TIMESTAMP = datetime.now().strftime("%Y-%m-%d_%H-%M-%S")
CSV_FILE = f"spektrofotometre_olcumleri_{RUN_TIMESTAMP}.csv"

app = Flask(__name__)

latest_data = {
    # Web panelde gösterilecek son ölçüm zamanı.
    "time": "-",

    # Ölçümün hangi örnek adına ait olduğunu tutar.
    "sample": "-",

    # TSL2591 sensöründen gelen ham görünür ışık değeri.
    "raw": 0.0,

    # Numuneden geçen ışık yüzdesi.
    "transmittance": 0.0,

    # Anlık absorbans değeri.
    "absorbance": 0.0,

    # Arduino tarafında hesaplanan ortalama absorbans değeri.
    "average_absorbance": 0.0,

    # Işık kapalı + kutu kapalı durumunda alınan karanlık referans.
    "dark_raw": 0.7,

    # Işık açık + kör/blank küvet durumunda alınan referans ışık değeri.
    "blank_raw": 1138.0,

    # Kullanıcıya gösterilecek sistem durumu.
    "status": "Arduino bağlantısı bekleniyor...",

    # Arduino bağlantısının aktif olup olmadığını gösterir.
    "connected": False,

    # CSV kayıt durumunu gösterir.
    "measuring": False,
}

# Web tabloda ve özet grafikte tutulacak ölçüm satırları.
data_rows = []

# Kullanıcının panelden seçtiği/girdiği güncel örnek adı.
current_sample_name = "Boş Küvet"

# Ölçüm kaydının aktif olup olmadığını gösterir.
measurement_enabled = False

# Arduino seri port nesnesi burada global tutulur.
# Böylece web paneldeki butonlar Arduino'ya SET_DARK / SET_BLANK komutu gönderebilir.
arduino_ser = None

# latest_data ve data_rows gibi ortak verileri thread çakışmasından korur.
state_lock = threading.Lock()

# Seri porta aynı anda birden fazla yazma/erişim olmaması için kullanılır.
serial_lock = threading.Lock()


# =========================================================
# CSV İŞLEMLERİ
# =========================================================

def prepare_csv():
    if not os.path.exists(CSV_FILE):
        with open(CSV_FILE, mode="w", newline="", encoding="utf-8-sig") as file:
            writer = csv.writer(file)
            writer.writerow([
                "Tarih-Saat",
                "Örnek Adı",
                "Raw Visible",
                "Transmittance (%)",
                "Absorbance",
                "Average Absorbance",
                "Dark Raw",
                "Blank Raw"
            ])


def save_to_csv(row):
    with open(CSV_FILE, mode="a", newline="", encoding="utf-8-sig") as file:
        writer = csv.writer(file)
        writer.writerow([
            row["time"],
            row["sample"],
            row["raw"],
            row["transmittance"],
            row["absorbance"],
            row["average_absorbance"],
            row.get("dark_raw", 0.0),
            row.get("blank_raw", 0.0)
        ])


def reset_csv():
    if os.path.exists(CSV_FILE):
        os.remove(CSV_FILE)
    prepare_csv()




# =========================================================
# ARDUINO KOMUT GÖNDERME VE REFERANS PARSE İŞLEMLERİ
# =========================================================

def send_arduino_command(command):
    """
    Web panelden gelen bir komutu Arduino'ya seri port üzerinden gönderir.

    Örnek komutlar:
    - SET_DARK  : Arduino ışık kapalıyken darkRaw değerini alır.
    - SET_BLANK : Arduino kör/blank küvet varken blankRaw değerini alır.
    - GET_REF   : Arduino mevcut darkRaw ve blankRaw değerlerini gönderir.
    - RESET_AVG : Arduino ortalama hesaplama tamponunu sıfırlar.
    """
    global arduino_ser

    # Seri port işlemleri aynı anda çakışmasın diye kilit kullanılır.
    with serial_lock:
        # Arduino henüz bağlı değilse komut gönderilemez.
        if arduino_ser is None or not arduino_ser.is_open:
            return False, "Arduino seri port bağlantısı yok."

        try:
            # Komut sonuna yeni satır eklenir. Arduino readStringUntil('\n') ile okur.
            arduino_ser.write((command.strip() + "\n").encode("utf-8"))

            # Komutun seri porta hemen gönderilmesi sağlanır.
            arduino_ser.flush()

            # Başarılı cevap döndürülür.
            return True, f"{command} komutu Arduino'ya gönderildi."

        except Exception as e:
            # Hata varsa kullanıcıya anlaşılır şekilde döndürülür.
            return False, f"Arduino'ya komut gönderilemedi: {e}"
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
